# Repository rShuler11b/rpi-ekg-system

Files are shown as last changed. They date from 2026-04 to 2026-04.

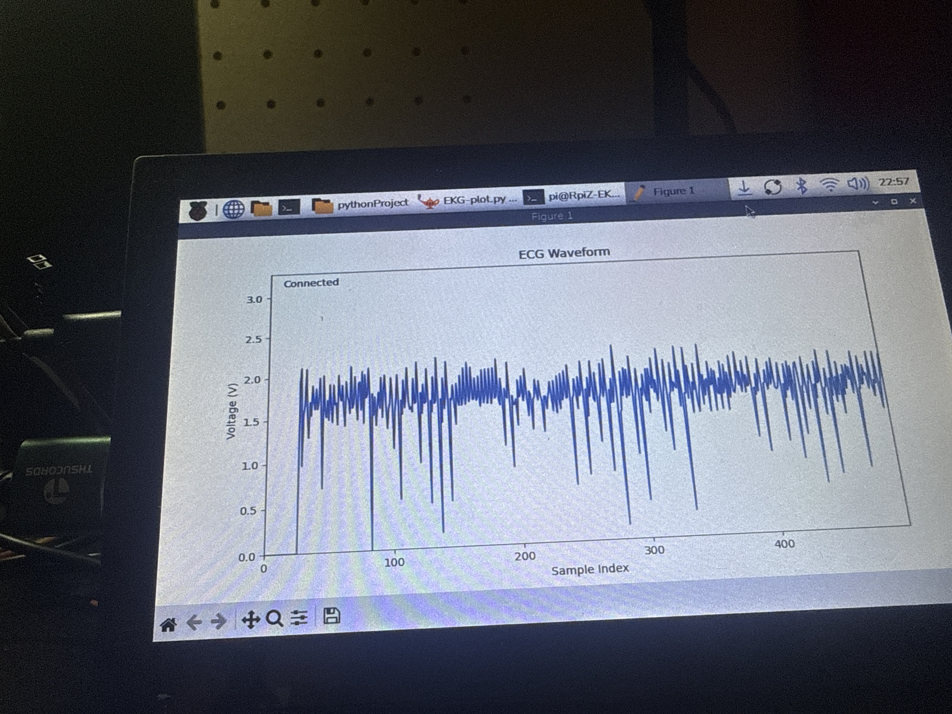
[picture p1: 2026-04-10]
Images/RALA_swapped.jpeg

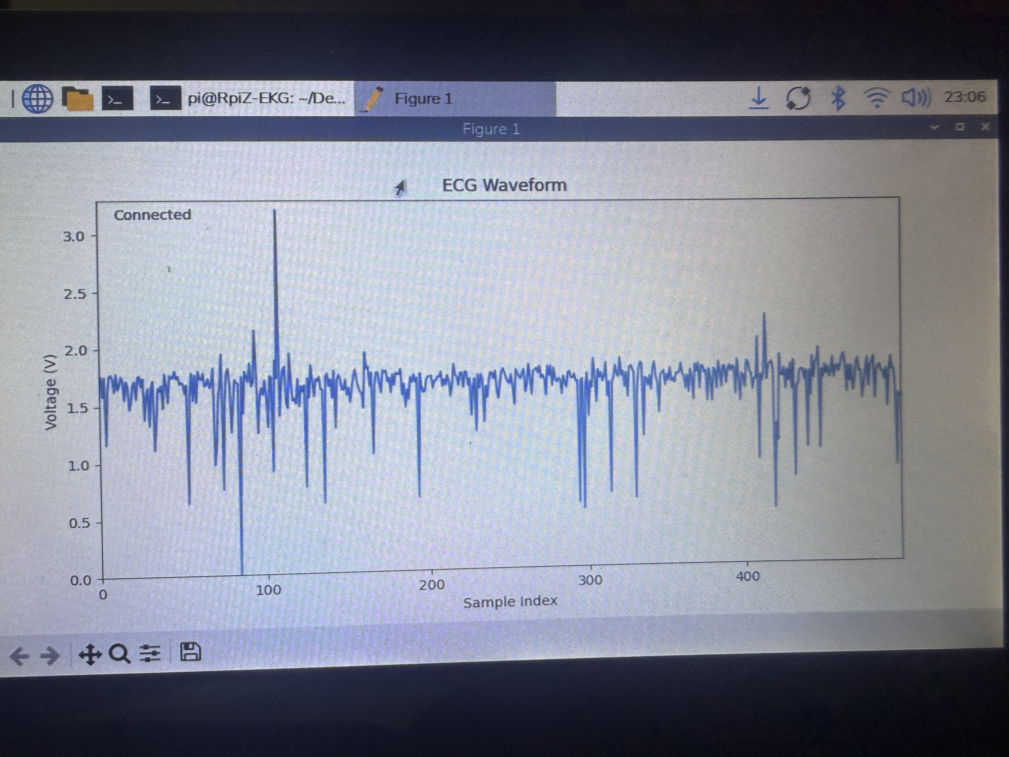
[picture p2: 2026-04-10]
Images/Correct_RAW.jpeg

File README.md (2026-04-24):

# Raspberry Pi 5 Embedded ECG System

## Overview

This project is a Raspberry Pi 5 based embedded ECG system using an AD8232 ECG front-end module and an MCP3202 SPI ADC.

The program performs:

- Real-time ECG acquisition
- Lead-off detection
- Digital filtering
- Pan Tompkins QRS detection
- Heart rate estimation
- Live plotting
- CSV recording

This project is for biomedical signal processing, embedded systems learning, and ECG algorithm development.

## Disclaimer

This project is for research and educational purposes only.

It is NOT a medical device and is not intended for:

- Diagnosis
- Treatment
- Patient monitoring
- Clinical decision-making

Use at your own risk.

## Project Structure

```text
├── main.py
├── adc.py
├── lead_off.py
├── filters.py
├── pan_tompkins.py
├── sampler.py
├── csv_writer.py
├── plotter.py
├── requirements.txt
├── README.md
```

## File Purpose

| File | Purpose |
|---|---|
| `main.py` | Starts the ECG program and connects all modules |
| `adc.py` | Handles MCP3202 SPI ADC reads |
| `lead_off.py` | Handles AD8232 LO+ and LO- detection |
| `filters.py` | Applies ECG filtering |
| `pan_tompkins.py` | Runs Pan Tompkins QRS detection |
| `sampler.py` | Owns the fixed-rate sampling loop |
| `csv_writer.py` | Records ECG samples to CSV |
| `plotter.py` | Handles live matplotlib display |
| `requirements.txt` | Lists Python dependencies |

## Hardware Used

- Raspberry Pi 5
- AD8232 ECG front-end module
- MCP3202 12-bit SPI ADC
- ECG electrodes
- Breadboard
- Jumper wires
- Optional RC anti-aliasing filter

## Raspberry Pi 5 SPI Wiring

### MCP3202 to Raspberry Pi 5

| MCP3202 Pin | Function | Raspberry Pi 5 Pin | GPIO | Wire Color |
|---|---|---:|---|---|
| VDD | Power | Pin 1 | 3.3V | Red |
| VREF | ADC reference | Pin 1 | 3.3V | Red |
| AGND | Ground | Pin 6 | GND | Black |
| DGND | Ground | Pin 6 | GND | Black |
| CLK | SPI clock | Pin 23 | GPIO11 / SCLK | Yellow |
| DOUT | SPI MISO | Pin 21 | GPIO9 / MISO | Purple |
| DIN | SPI MOSI | Pin 19 | GPIO10 / MOSI | Blue |
| CS/SHDN | SPI chip select | Pin 24 | GPIO8 / CE0 | Orange |
| CH0 | ECG input | AD8232 OUTPUT | Signal wire | Green |

## AD8232 Wiring

| AD8232 Pin | Connects To | Raspberry Pi / ADC Pin | Wire Color |
|---|---|---|---|
| 3.3V | Power | Pi Pin 1, 3.3V | Red |
| GND | Ground | Pi Pin 6, GND | Black |
| OUTPUT | ECG analog output | MCP3202 CH0 | Green |
| LO+ | Lead-off positive | Pi GPIO17, Pin 11 | White |
| LO- | Lead-off negative | Pi GPIO27, Pin 13 | Gray |
| SDN | Shutdown control | Pi 3.3V | Red |

SDN should be tied HIGH to keep the AD8232 enabled.

## Optional RC Anti-Aliasing Filter

Place the RC filter between the AD8232 OUTPUT pin and MCP3202 CH0.

Recommended starting values:

```text
R = 10 kOhm
C = 0.33 uF
```

Wiring:

```text
AD8232 OUTPUT ---- 10 kOhm resistor ---- MCP3202 CH0
                                      |
                                   0.33 uF
                                      |
                                     GND
```

This creates a simple passive low-pass filter before the ADC. It helps reduce high-frequency noise before sampling.

## Enable SPI on Raspberry Pi 5

Run:

```bash
sudo raspi-config
```

Then go to:

```text
Interface Options -> SPI -> Enable
```

Reboot:

```bash
sudo reboot
```

Check that SPI is available:

```bash
ls /dev/spidev*
```

Expected output:

```text
/dev/spidev0.0
/dev/spidev0.1
```

## Install Dependencies

From the project folder:

```bash
cd ~/Desktop/rpi_EKG/rpi-ecg
python3 -m venv .venv
source .venv/bin/activate
pip install -r requirements.txt
```

## How to Run

From the project folder:

```bash
cd ~/Desktop/rpi_EKG/rpi-ecg
source .venv/bin/activate
python main.py
```

The program will:

1. Open the MCP3202 SPI device
2. Start ECG sampling
3. Apply filtering
4. Run Pan Tompkins QRS detection
5. Plot the filtered ECG signal with QRS markers
6. Save ECG data to CSV

## Algorithm Pipeline

```text
AD8232 ECG Signal
        |
        v
MCP3202 ADC
        |
        v
Raw Voltage Sample
        |
        v
Digital Filter Chain
        |
        v
Pan Tompkins Processing
        |
        v
QRS Detection + Heart Rate Estimate
        |
        v
Live Plot + CSV Recording
```

## Filtering Pipeline

```text
raw ECG
   |
   v
high-pass filter
   |
   v
low-pass filter
   |
   v
60 Hz notch filter
   |
   v
filtered ECG
```

The high-pass filter reduces baseline drift, the low-pass filter reduces high-frequency noise, and the notch filter reduces 60 Hz powerline interference.

## Pan Tompkins Pipeline

The Pan Tompkins detector uses this sequence:

```text
filtered ECG
   |
   v
derivative
   |
   v
squaring
   |
   v
moving window integration
   |
   v
adaptive thresholding
   |
   v
QRS detection
   |
   v
RR interval + heart rate estimate
```

| Stage | Purpose |
|---|---|
| Derivative | Emphasizes steep QRS slopes |
| Squaring | Makes all values positive and exaggerates large changes |
| Moving window integration | Measures QRS energy over a short time window |
| Adaptive thresholding | Separates likely QRS events from noise |
| Refractory period | Prevents double-counting the same heartbeat |
| RR interval calculation | Estimates heart rate from time between detected beats |

## Pan Tompkins References

This implementation is based on the original Pan Tompkins QRS detection method and a Python reference implementation.

- Pan, Jiapu, and Willis J. Tompkins. A Real-Time QRS Detection Algorithm. IEEE Transactions on Biomedical Engineering, 1985.
- Oxford copy of the Pan Tompkins paper: https://www.robots.ox.ac.uk/~gari/teaching/cdt/A3/readings/ECG/Pan+Tompkins.pdf
- Python reference implementation: https://github.com/Pramod07Ch/Pan-Tompkins-algorithm-python/blob/main/Pan_tompkins_algorithm.py

## CSV Recording

The program records sample data during runtime.

CSV fields:

```text
sample_index
timestamp_seconds
raw_voltage
filtered_voltage
pan_tompkins_integrated
qrs_detected
heart_rate_bpm
lead_off
```

Example row:

```text
1520,7.600000,1.512300,0.084100,0.02170000,1,72.40,0
```

## Lead-Off Detection

The AD8232 provides two lead-off pins:

```text
LO+
LO-
```

If either pin goes HIGH, the program treats the ECG leads as disconnected.

When lead-off is detected:

- The sample is marked with `lead_off = 1`
- QRS detection is ignored
- Filter state is reset
- Pan Tompkins threshold state is reset
- The CSV still records the event

## Sampling Rate

Default sampling rate:

```text
200 Hz
```

This means:

```text
sample interval = 0.005 seconds
```

A stable sampling rate matters because ECG timing is used for RR intervals and heart rate estimation.

## Notes

- Keep ECG wires short when possible.
- Use a shared ground between the Pi, MCP3202, and AD8232.
- Use 3.3V logic only.
- Do not connect ECG electrodes to wall-powered test equipment.
- Battery power is safer for early testing.
- This system is for learning and research only.

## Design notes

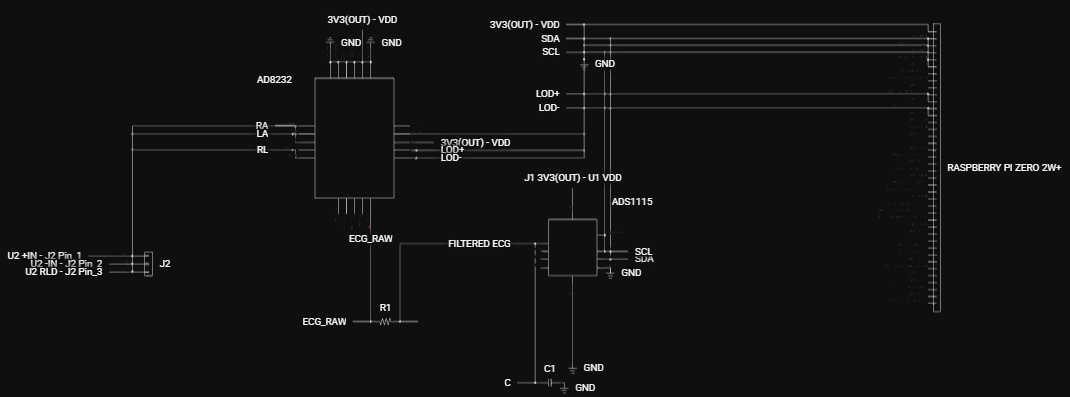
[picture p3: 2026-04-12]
Hardware_KiCad/Circuit_V1.0.png

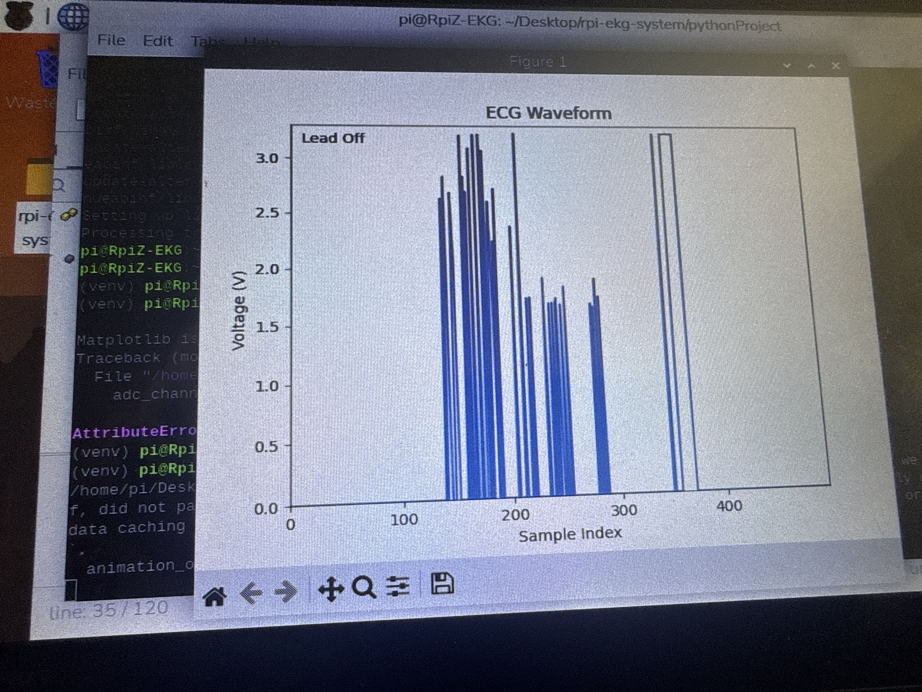
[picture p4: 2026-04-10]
Images/SDN_floating.jpeg

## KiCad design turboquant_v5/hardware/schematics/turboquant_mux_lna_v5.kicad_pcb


Board: 4 copper layers, 100.0 x 80.0 mm, 25 parts (0 on the bottom side), 3 nets.

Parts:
F1: 2A; Fuse_1206_3216Metric
J1: 12V_Input; TerminalBlock_bornier-2_P5.08mm
J2: TX_BUS; SMA_EDGE
J3: E1_GPIO; PinHeader_2x10_P2.54mm_Vertical
J4: RX0_OUT; SMA_EDGE
J5: RX1_OUT; SMA_EDGE
Q9, Q10, Q11, Q12, Q13, Q14, Q15, Q16: IRF830; TO-220-3_Vertical
U1: LM7805; TO-252-2
U2: AMS1117-3.3; SOT-223-3_TabPin2
U3, U4: DG408; SOIC-16_3.9x9.9mm_P1.27mm
U5: 74HCT595; SOIC-16_3.9x9.9mm_P1.27mm
U6, U7: OPA1641; SOIC-8_3.9x4.9mm_P1.27mm
U8, U9, U10, U11: TC4427; SOIC-8_3.9x4.9mm_P1.27mm

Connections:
+5V: U1.3, U2.3
+12V: F1.1, F1.2, J1.1, U1.1
GND: J1.2, J2.2, J4.2, J5.2, U1.2, U2.1

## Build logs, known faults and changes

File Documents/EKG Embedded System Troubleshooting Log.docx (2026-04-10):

EKG Embedded System Troubleshooting Log

Purpose

This document tracks real problems encountered during development of the Raspberry Pi–based EKG system, along with root causes and implemented solutions. It serves as both a debugging reference and a foundation for future design improvements and research documentation.

1. AD8232 Power Verification Failure

Problem
The AD8232 showed no LED activity, making it unclear whether the chip was powered.

Observed Behavior

- No blinking LED
- No measurable output signal

Root Cause
Power delivery through jumper wires was assumed but not verified. Breadboard connections can be unreliable, especially with loose Dupont connectors.

Solution

- Used a multimeter to probe VCC and GND directly at the chip pins
- Confirmed ~3.3 V supply
- Ensured all grounds (Pi, ADC, AD8232) shared a common reference

Takeaway
Always verify power electrically, not visually. LEDs are not sufficient indicators of proper operation.

2. Incorrect or Non-Physiological ECG Waveform

Problem
The output waveform did not resemble a recognizable ECG signal.

Observed Behavior

- Irregular spikes
- No clear P-QRS-T structure

Root Cause

- Improper electrode placement
- Incorrect lead configuration
- Poor skin contact or inconsistent grounding

Solution

- Standardized electrode placement (RA(blue), LA(red), RL(black) configuration)
- Ensured firm adhesion using clinical-grade electrodes
- Verified continuity through the 3.5 mm lead cable

Takeaway
Signal acquisition quality is dominated by electrode placement and contact.

3. Constant Lead-Off Detection

Problem
The system continuously reported lead-off conditions even when electrodes were attached.

Observed Behavior

- LO+ / LO− signals triggered constantly
- No stable ECG output

Root Cause

- GPIO pins not properly configured
- Weak or inconsistent electrode contact

Solution

- Configured GPIO pins with internal pull-ups
- Verified wiring from AD8232 LO pins to Raspberry Pi GPIO
- Replaced or repositioned electrodes to improve contact

Takeaway
Lead-off detection is sensitive to both electrical configuration and physical contact quality.

4. Excessive Noise and Motion Artifact

Problem
The ECG signal was highly noisy and degraded significantly with movement.

Observed Behavior

- High-frequency jitter
- Large baseline shifts during motion
- Signal distortion during patient movement

Root Cause

- Motion-induced electrode impedance changes
- Environmental electrical noise
- Lack of filtering pipeline

Solution

- Implemented software filtering:
  - Baseline removal (high-pass behavior)
  - Smoothing filter (low-pass behavior)
- Improved wire stability and strain relief
- Identified IMU-based correction as a future enhancement

Takeaway
Motion artifact is a dominant challenge in real-world ECG systems and must be addressed at both hardware and software levels.

5. Flatline Signal Due to SDN Pin Misconfiguration

Problem
The ECG signal appeared flat (no waveform) but would produce spikes when the leads were shorted or disturbed.

Observed Behavior

- Constant flatline output
- Spikes only when leads were touched or shorted

Root Cause
The SDN (shutdown) pin on the AD8232 was not tied to 3.3 V. This kept the chip in a disabled or inactive state, preventing normal signal amplification.

Solution

- Tied the SDN pin directly to 3.3 V
- Verified the chip exited shutdown mode
- Confirmed normal ECG waveform appeared after correction

Takeaway
Critical control pins like SDN must be explicitly set. A floating or low SDN pin will disable the analog front end and produce misleading flatline behavior.

6. ADS1115 Not Producing Expected Data

Problem
ADC readings were inconsistent or not appearing as expected.

Observed Behavior

- No data or incorrect values

Root Cause

- I2C misconfiguration
- Incorrect channel selection

Solution

- Verified device presence using i2cdetect -y 1
- Confirmed correct I2C address (typically 0x48)
- Used correct channel index (0 for A0)

Takeaway
Always verify communication layer before debugging signal quality.

7. ADS1115 Library Attribute Error

Problem
Error: ADS1115 has no attribute P0

Observed Behavior

- Program crashes at channel initialization

Root Cause
Library API differences or incorrect usage

Solution

- Replaced symbolic constant with integer channel index:
  - AnalogIn(adc_device, 0)

Takeaway
Library abstractions can vary. Always confirm expected API usage.

8. Raw ADC Output Appeared Random

Problem
Terminal output appeared as random or meaningless values.

Observed Behavior

- Rapidly changing numbers
- No obvious waveform structure

Root Cause

- Raw ADC values were being printed without scaling or filtering
- Noise present in signal

Solution

- Interpreted values as sampled voltage
- Added filtering and visualization (plotting)

Takeaway
Raw biosignals are not human-readable without processing.

9. Python Environment and Dependency Issues

Problem
Errors occurred when installing required libraries such as busio.

Observed Behavior

- pip install failures
- "externally managed environment" errors

Root Cause
System Python restrictions on Raspberry Pi OS

Solution

- Created a Python virtual environment
- Installed all dependencies within the virtual environment

Takeaway
Use isolated environments for embedded Python development to avoid system conflicts.

10. Baseline Drift in ECG Signal

Problem
The ECG signal slowly drifted upward or downward over time.

Observed Behavior

- Signal baseline not centered
- Long-term trend shifts

Root Cause

- Electrode polarization
- Low-frequency physiological and environmental noise

Solution

- Implemented baseline tracking using a slow-moving average
- Subtracted this baseline from the raw signal

Takeaway
Baseline drift must be removed for meaningful ECG interpretation.

11. High-Frequency Noise and Jitter

Problem
The signal contained significant high-frequency fluctuations.

Observed Behavior

- Jagged waveform
- Poor readability of cardiac features

Root Cause

- Electrical interference
- ADC quantization noise

Solution

- Applied smoothing filter (low-pass behavior)
- Tuned smoothing parameter for balance between clarity and responsiveness

Takeaway
Filtering is required to extract clinically useful information from raw signals.

12. Lack of Real-Time Filtering Pipeline

Problem
Initial system displayed only raw ECG data.

Observed Behavior

- Noisy, unstable waveform

Root Cause
No signal processing pipeline implemented

Solution

- Built real-time filtering chain:
  1. Baseline removal (high-pass behavior)
  2. Smoothing filter (low-pass behavior)

Takeaway
A minimal signal processing pipeline is required for any usable ECG display.

Future Additions

- IMU-based motion artifact correction
- Hardware filtering (RC filters, shielding)
- Improved electrode interface design
- Real-time feature extraction (QRS detection)

End of document

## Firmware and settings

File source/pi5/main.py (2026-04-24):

# ============================================================
# Name: Ryan Shuler
# Project: Raspberry Pi 5 Embedded ECG System
# File: main.py
#
# Description:
#   Main entry point for the Raspberry Pi 5 ECG program.
#   This file creates the hardware, processing, sampling, CSV,
#   and plotting objects, then starts the worker threads.
# ============================================================

import queue
import signal
import threading
from collections import deque

from adc import MCP3202Reader
from lead_off import LeadOffDetector
from filters import ECGFilterChain
from pan_tompkins import PanTompkinsDetector
from sampler import ECGSampler
from csv_writer import ECGCSVWriter
from plotter import ECGPlotter


# ------------------------------------------------------------
# USER SETTINGS
# ------------------------------------------------------------

BUFFER_SIZE_NUMBER_OF_SAMPLES = 500
SAMPLE_INTERVAL_SECONDS = 0.005          # 0.005 seconds = 200 Hz
SAMPLING_FREQUENCY_HZ = 1.0 / SAMPLE_INTERVAL_SECONDS

ADC_CHANNEL_NUMBER = 0
MCP3202_REFERENCE_VOLTAGE = 3.3
SPI_BUS_NUMBER = 0
SPI_CHIP_SELECT_NUMBER = 0
SPI_CLOCK_SPEED_HZ = 500000

PLOT_Y_AXIS_MINIMUM = -0.5
PLOT_Y_AXIS_MAXIMUM = 0.5
PLOT_REFRESH_INTERVAL_MILLISECONDS = 50

TERMINAL_PRINT_EVERY_N_SAMPLES = 20
RECORDINGS_DIRECTORY = "recordings"

CSV_WRITER_STOP_SENTINEL = None


# ------------------------------------------------------------
# MAIN PROGRAM
# ------------------------------------------------------------

def csv_writer_loop(csv_queue, csv_writer, stop_sentinel):
    """
    Pulls queued sample rows and writes them to the CSV file.

    This runs in its own thread so that file writes do not interrupt
    fixed-rate ECG sampling.
    """
    while True:
        row = csv_queue.get()

        if row is stop_sentinel:
            # Drain remaining rows before exiting. This prevents the last
            # samples from being lost during shutdown.
            while not csv_queue.empty():
                remaining_row = csv_queue.get_nowait()
                if remaining_row is not stop_sentinel:
                    csv_writer.write_row(*remaining_row)
            break

        csv_writer.write_row(*row)


def main():
    """Builds the ECG system objects and starts the program."""

    # Shared buffers. Deque with maxlen acts like a circular buffer.
    raw_voltage_buffer = deque(
        [0.0] * BUFFER_SIZE_NUMBER_OF_SAMPLES,
        maxlen=BUFFER_SIZE_NUMBER_OF_SAMPLES
    )
    filtered_voltage_buffer = deque(
        [0.0] * BUFFER_SIZE_NUMBER_OF_SAMPLES,
        maxlen=BUFFER_SIZE_NUMBER_OF_SAMPLES
    )
    integrated_buffer = deque(
        [0.0] * BUFFER_SIZE_NUMBER_OF_SAMPLES,
        maxlen=BUFFER_SIZE_NUMBER_OF_SAMPLES
    )
    qrs_marker_buffer = deque(
        [None] * BUFFER_SIZE_NUMBER_OF_SAMPLES,
        maxlen=BUFFER_SIZE_NUMBER_OF_SAMPLES
    )
    heart_rate_buffer = deque(
        [0.0] * BUFFER_SIZE_NUMBER_OF_SAMPLES,
        maxlen=BUFFER_SIZE_NUMBER_OF_SAMPLES
    )

    # Threading objects.
    data_lock = threading.Lock()
    stop_event = threading.Event()
    csv_queue = queue.Queue()

    adc_reader = None
    lead_off_detector = None
    csv_writer = None
    sampler_thread = None
    writer_thread = None
    previous_sigint_handler = None

    try:
        # Hardware objects.
        adc_reader = MCP3202Reader(
            bus_number=SPI_BUS_NUMBER,
            chip_select_number=SPI_CHIP_SELECT_NUMBER,
            reference_voltage=MCP3202_REFERENCE_VOLTAGE,
            clock_speed_hz=SPI_CLOCK_SPEED_HZ
        )

        lead_off_detector = LeadOffDetector()

        # Processing objects.
        filter_chain = ECGFilterChain(
            sampling_frequency_hz=SAMPLING_FREQUENCY_HZ
        )

        qrs_detector = PanTompkinsDetector(
            sampling_frequency_hz=SAMPLING_FREQUENCY_HZ
        )

        # CSV object.
        csv_writer = ECGCSVWriter(recordings_directory=RECORDINGS_DIRECTORY)
        print(f"Recording to: {csv_writer.file_path}")

        # Sampling object.
        sampler = ECGSampler(
            adc_reader=adc_reader,
            lead_off_detector=lead_off_detector,
            filter_chain=filter_chain,
            qrs_detector=qrs_detector,
            csv_queue=csv_queue,
            data_lock=data_lock,
            stop_event=stop_event,
            raw_voltage_buffer=raw_voltage_buffer,
            filtered_voltage_buffer=filtered_voltage_buffer,
            integrated_buffer=integrated_buffer,
            qrs_marker_buffer=qrs_marker_buffer,
            heart_rate_buffer=heart_rate_buffer,
            sample_interval_seconds=SAMPLE_INTERVAL_SECONDS,
            adc_channel_number=ADC_CHANNEL_NUMBER,
            terminal_print_every_n_samples=TERMINAL_PRINT_EVERY_N_SAMPLES
        )

        # Plotting object.
        plotter = ECGPlotter(
            data_lock=data_lock,
            stop_event=stop_event,
            filtered_voltage_buffer=filtered_voltage_buffer,
            qrs_marker_buffer=qrs_marker_buffer,
            heart_rate_buffer=heart_rate_buffer,
            buffer_size_number_of_samples=BUFFER_SIZE_NUMBER_OF_SAMPLES,
            y_axis_minimum=PLOT_Y_AXIS_MINIMUM,
            y_axis_maximum=PLOT_Y_AXIS_MAXIMUM,
            refresh_interval_milliseconds=PLOT_REFRESH_INTERVAL_MILLISECONDS
        )

        # Install a Ctrl-C (SIGINT) handler so a keyboard interrupt from
        # the terminal sets stop_event instead of propagating as a bare
        # KeyboardInterrupt. Without this, the only clean way to stop the
        # program is to close the matplotlib window. If the plot window
        # ever becomes unresponsive, Ctrl-C in the terminal still brings
        # the whole pipeline down through the normal shutdown path.
        #
        # The handler is installed here, after all objects exist but
        # before the worker threads are started, so the stop_event is
        # guaranteed to be valid at the moment the signal could fire.
        def handle_sigint(signal_number, current_frame):
            print("\nCtrl-C received. Shutting down...")
            stop_event.set()

        previous_sigint_handler = signal.signal(signal.SIGINT, handle_sigint)

        # Start the writer thread first so CSV rows can be accepted as soon
        # as the sampler starts producing data.
        writer_thread = threading.Thread(
            target=csv_writer_loop,
            args=(csv_queue, csv_writer, CSV_WRITER_STOP_SENTINEL),
            daemon=False
        )
        writer_thread.start()

        sampler_thread = threading.Thread(
            target=sampler.run,
            daemon=False
        )
        sampler_thread.start()

        # plt.show() blocks until the user closes the plot window.
        plotter.show()

    finally:
        # Signal threads to stop.
        stop_event.set()

        if sampler_thread is not None:
            sampler_thread.join(timeout=2.0)

        if csv_queue is not None:
            csv_queue.put(CSV_WRITER_STOP_SENTINEL)

        if writer_thread is not None:
            writer_thread.join(timeout=5.0)

        if csv_writer is not None:
            csv_writer.close()
            print("Recording file closed.")

        if adc_reader is not None:
            adc_reader.close()
            print("SPI device closed.")

        if lead_off_detector is not None:
            lead_off_detector.close()
            print("Lead-off GPIO pins released.")

        # Restore whatever SIGINT handler was in place before main() ran.
        # This keeps main() polite if it is ever imported and called from
        # a larger program rather than executed as __main__.
        if previous_sigint_handler is not None:
            signal.signal(signal.SIGINT, previous_sigint_handler)

        print("ECG program stopped.")


if __name__ == "__main__":
    main()

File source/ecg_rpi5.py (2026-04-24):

# ============================================================
# Name: Ryan Shuler
# Project: Embedded ECG Monitoring System
# File: ecg_rpi5.py
#
# Description:
#   This program reads ECG voltage data from the MCP3202 ADC
#   over SPI, applies real-time digital filtering, displays
#   only the filtered ECG signal using matplotlib, and records
#   ECG data to a CSV file during runtime.
#
# Hardware:
#   - Raspberry Pi 5
#   - AD8232 ECG Front End
#   - MCP3202 ADC (SPI)
#
# Filters Implemented:
#   1. High-pass filter  — baseline drift removal   (fc ≈ 0.32 Hz)
#   2. Low-pass filter   — high-frequency smoothing (fc ≈ 40 Hz)
#   3. 60 Hz notch filter — powerline interference removal
#
# Filter constant derivation (all for fs = 200 Hz):
#
#   High-pass alpha:
#       alpha = 1 / (1 + 2*pi*fc/fs)  [first-order IIR approximation]
#       fc = 0.32 Hz → alpha ≈ 0.98
#       Retains all cardiac signal content while blocking DC and
#       very slow baseline wander (respiration, electrode drift).
#
#   Low-pass beta:
#       beta = 1 - exp(-2*pi*fc/fs)
#       fc = 40 Hz → beta ≈ 0.73
#       Preserves QRS energy (dominant content up to ~40 Hz) while
#       attenuating high-frequency noise above that band.
#       
#
#   Notch angular frequency:
#       w0 = 2*pi*60/200 = 1.885 rad/sample
#       Coefficients are computed at startup from fs and target
#       frequency, so they stay correct as long as fs is accurate.
#
# Filter chain order:
#   raw → high-pass → low-pass → notch
#   High-pass removes DC first so the notch operates on a
#   zero-centered signal, which improves its numerical stability.
#
# Thread architecture:
#   - Sampling thread:  owns SPI reads, filtering, buffer writes,
#                       and posting samples to the CSV write queue.
#                       Uses cumulative perf_counter timing to avoid
#                       drift from per-iteration sleep resets.
#   - CSV writer thread: drains the write queue and flushes to disk.
#                       Decoupled from sampling so filesystem stalls
#                       (slow SD card, sync pressure) cannot disrupt
#                       sample timing or RR interval accuracy.
#   - Main thread:      owns the matplotlib event loop and plot
#                       animation. Reads shared buffer under lock.
#                       Never touches the ADC or filters.
#
# Output:
#   - Live graph of FILTERED ECG only
#   - Terminal output of labeled raw and filtered data
#   - CSV recording of sample number, timestamp, raw voltage,
#     filtered voltage, and lead-off flag
#
# Notes:
#   - Lead-off pins use pull-down resistors (active-high signal)
#   - Plot y-axis is fixed for a stable visual reference
#   - MCP3202 is a 12-bit SPI ADC (0–4095 counts → 0–3.3 V)
#   - Pi 5 uses the RP1 I/O controller; verify /dev/spidev0.0
#     exists and spidev overlays are enabled in /boot/firmware/config.txt
# ============================================================

import math
import time
import queue
import threading
from collections import deque

import board
from digitalio import DigitalInOut, Direction, Pull
import spidev

import matplotlib.pyplot as plt
import matplotlib.animation as animation

from recording_utils import (
    open_recording_file,
    append_sample_to_csv,
    close_recording_file
)


# ------------------------------------------------------------
# USER SETTINGS
# ------------------------------------------------------------

# Display buffer: how many samples are visible in the live plot.
# At 200 Hz, 500 samples = 2.5 seconds of waveform.
buffer_size_number_of_samples = 500

# Target sample interval. 0.005 s = 200 Hz.
# Verify this is being achieved by checking timestamp diffs in CSV.
sample_time_interval_seconds = 0.005

# ------------------------------------------------------------
# FILTER PARAMETERS
# All constants are derived for fs = 200 Hz.
# If you change sample_time_interval_seconds, recalculate these.
# See derivation notes in the file header above.
# ------------------------------------------------------------

# High-pass: blocks DC and baseline wander below ~0.32 Hz
high_pass_alpha = 0.98

# Low-pass: attenuates noise above ~40 Hz while preserving QRS shape.
# Raised from 0.2 (fc ≈ 7 Hz) to 0.73 (fc ≈ 40 Hz).
# Lower values smooth more aggressively but flatten QRS peaks.
low_pass_beta = 0.73

# Notch filter: targets 60 Hz powerline interference.
# Radius controls notch width. 0.98 = narrow (precise), 0.90 = wide.
# Narrower is better when 60 Hz is the only interference; widen if
# harmonics or frequency drift are observed in the FFT of recordings.
notch_filter_frequency_hz = 60.0
notch_filter_radius = 0.98

# ------------------------------------------------------------
# DISPLAY SETTINGS
# ------------------------------------------------------------

# Y-axis bounds for the live plot (volts, filtered signal).
# After the low-pass beta change, filtered peaks may be larger than
# before. Widen these bounds if peaks are clipping off-screen.
plot_y_axis_minimum = -0.5
plot_y_axis_maximum = 0.5

# How often the live plot redraws. 50 ms = 20 fps, low CPU cost.
# The plot reads from the shared buffer; it does not affect sample rate.
plot_refresh_interval_milliseconds = 50

# Print one terminal line every N samples to avoid console flooding.
terminal_print_every_n_samples = 20

# ------------------------------------------------------------
# MCP3202 ADC AND SPI SETTINGS
# ------------------------------------------------------------

mcp3202_reference_voltage = 3.3     # Volts applied to VREF pin
mcp3202_channel_number = 0          # 0 or 1

spi_bus_number = 0
spi_chip_select_number = 0
spi_clock_speed_hz = 500000         # 500 kHz; MCP3202 max is 1.8 MHz at 3.3V
                                    # Increase cautiously if timing is tight

# ------------------------------------------------------------
# CSV WRITER QUEUE
# The sampling thread enqueues row tuples here.
# The CSV writer thread drains this queue and writes to disk.
# Queue is unbounded — in practice it stays near-empty at 200 Hz,
# but will buffer safely during any brief filesystem stall.
# ------------------------------------------------------------
csv_write_queue = queue.Queue()

# Sentinel value that signals the writer thread to exit cleanly.
_CSV_WRITER_STOP_SENTINEL = None


# ------------------------------------------------------------
# SETUP SPI AND MCP3202 ADC
# ------------------------------------------------------------
spi_device = spidev.SpiDev()
spi_device.open(spi_bus_number, spi_chip_select_number)
spi_device.max_speed_hz = spi_clock_speed_hz
spi_device.mode = 0b00              # MCP3202 uses SPI mode 0,0
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

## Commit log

2026-04-10 Updated A0 channel. 0 = channel A0
    [rpi_ekg_system.kicad_pcb, rpi_ekg_system.kicad_sch]
2026-04-10 Add real-time ECG filtering pipeline with live visualization and labeled data output
    Implement high-pass, low-pass, and 60 Hz notch filters for live signal conditioning
    Display both RAW and FILTERED ECG traces simultaneously in matplotlib
    Add labeled terminal output for raw and filtered voltage values
    Improve code readability with clearer variable names and expanded comments
    [rpi_ekg_system.kicad_pcb, rpi_ekg_system.kicad_sch]
2026-04-11 Improve ECG plot performance and visualization clarity
    Increase plot update rate by reducing animation interval
    Enable blitting for faster rendering of filtered ECG waveform
    Remove raw ECG trace from plot and retain terminal output only
    Set fixed y-axis limits for stable waveform visualization
    Switch lead-off detection pins to pull-down configuration
    Reduce terminal output frequency to improve runtime performance
    Update documentation and comments to reflect optimized display behavior
    [EKG-plot.py]
2026-04-12 Add CSV recording pipeline to ECG system.
    Created recording_utils module to handle file creation, header writing, and row appending for ECG data.
    Integrated recording into main loop with clear separation between signal processing, recording activity, and display buffering.
    Each sample is logged with sample index, timestamp, raw voltage, filtered voltage, and lead-off flag.
    Added timestamp-based filenames and safe file closure to prevent data loss.
    [EKG-test.py, recording_utils.py, rpi-ecg.py]
2026-04-12 added image of circuit version 1
2026-04-19 adjusting filters and first logs
    [session_2026_04_12_20_30_47.csv, session_2026_04_12_20_35_51.csv, session_2026_04_12_20_43_23.csv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]
2026-04-23 updated readme to include Rpi 5 to include mcp3202(SPI). Added ecg_rpi5.py that runs ECG over SPI for comparison to I2C
2026-04-24 Refactor ECG system into modular architecture
    Split monolithic ecg_rpi5.py into separate modules for ADC, lead-off detection, filtering, Pan Tompkins processing, sampling, CSV writing, and plotting
    Introduced Pan Tompkins QRS detection pipeline including derivative, squaring, moving window integration, adaptive thresholding, and refractory period handling
    Preserved existing sampling thread timing, filtering behavior, and CSV recording while improving separation of concerns and maintainability
    Added structured project layout with main entry point and requirements file for easier setup and extension
